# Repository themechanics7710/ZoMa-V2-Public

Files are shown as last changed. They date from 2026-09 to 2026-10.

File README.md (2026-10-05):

# ZoMa

**ZoMa** is a hand-built, differential-drive home robot with an onboard AI
assistant — **ZoMa Brain** — that can see, listen, talk, and eventually navigate
an apartment on its own. It's built from raw acrylic sheet with no laser cutter or
CNC machine: just a ruler, a blade, and a small pile of off-the-shelf electronics.

This repository is the complete, public source for the build: firmware, onboard
software, the AI backend, the web dashboard, and the mechanical design files.
The full build is documented as a 20-episode video series on
[**TheMechanics-Lab on YouTube**](https://www.youtube.com/@TheMechanics-Lab) —
[**watch the full series**](https://www.youtube.com/playlist?list=PLYKqW37Mjvkg).

---

## Build ZoMa with an AI partner

This repo ships a prompt, [`ZOMA_AI_PARTNER.md`](ZOMA_AI_PARTNER.md), that turns
Claude into a day-by-day build coach for ZoMa — it reads the repo's own docs as
its source of truth, never invents specs, and speaks whatever language you
write in. Three ways to use it:

1. **Claude Chat** — download the prompt file (raw link:
   [`ZOMA_AI_PARTNER.md`](https://raw.githubusercontent.com/themechanics7710/ZoMa-V2-Public/main/ZOMA_AI_PARTNER.md)),
   create a Claude Project, paste the file's contents in as the project's
   custom instructions, and give the project access to this repo (a GitHub
   connector in the project's knowledge, or just attach
   [`docs/PROGRAM.md`](docs/PROGRAM.md), [`docs/EQUIPMENT.md`](docs/EQUIPMENT.md),
   and whichever files cover your current day). Then send: **"I'm starting
   the ZoMa build."**
2. **Claude Code** — clone the repo and run Claude Code inside it:
   ```bash
   git clone https://github.com/themechanics7710/ZoMa-V2-Public.git
   cd ZoMa-V2-Public
   claude
   ```
   `CLAUDE.md` loads the coach automatically. Then say: **"I'm starting the
   ZoMa build."**
3. **Any other AI assistant** — paste `ZOMA_AI_PARTNER.md` as your first
   message and attach the relevant docs yourself.

Each session, the coach will: recap where you left off, scope what today
covers (and what it doesn't), point you to the right YouTube episode, check
you have the day's parts from `EQUIPMENT.md`, walk you through the build one
step at a time, run that day's checkpoint before calling it done, and leave
you a one-line teaser for tomorrow — crediting TheMechanics as the build's
designer throughout.

**No local GPU for the off-board AI machine?** You can still build ZoMa —
just ask your AI partner to adapt the code to run on a public AI API (like
Claude) instead of a local model. It's a DIY adaptation, not a path
TheMechanics has built or tested, but the coach can walk you through it.

ZoMa is designed and built by **TheMechanics**; the full series lives on
[TheMechanics-Lab](https://www.youtube.com/@TheMechanics-Lab) —
[watch the full series](https://www.youtube.com/playlist?list=PLYKqW37Mjvkg).

---

## What ZoMa does

- **Sees and hears** through an onboard camera and a far-field microphone array,
  streamed to an off-board GPU machine for real-time processing.
- **Talks back** with a voice pipeline (speech-to-text → LLM → text-to-speech)
  that supports interrupting it mid-sentence, and a tiered inference system —
  instant canned replies for simple things, a fast local model for everyday
  conversation, and a larger model for anything that needs deeper reasoning.
- **Shows its state** through a 40-LED ring (SparkFun LuMini, APA102) that lights
  up differently depending on whether it's listening, thinking, or speaking — so
  interacting with it feels less like talking to a black box.
- **Drives manually** too, over a PS5 DualSense controller paired to a dedicated
  ESP32 transmitter, relayed to the robot over a low-latency ESP-NOW link.

It's built with room to grow: the chassis reserves space and power for a second
battery and a robotic arm, without needing a redesign. Autonomous navigation
(lidar-based SLAM + Nav2 path planning, over ROS 2) is planned for a second
build season and isn't implemented yet — see
[docs/EQUIPMENT.md](docs/EQUIPMENT.md).

## How the robot is put together

At a glance: two ESP32 microcontrollers handle real-time control (driving the
motors, reading the encoders and IMU, receiving the controller input), a
Raspberry Pi 4 handles onboard I/O (camera, microphone array, and talking to the
ESP32s over micro-ROS), and an off-board machine with a GPU does the heavy
lifting for AI (speech recognition, the language model, vision, and text-to-speech).
A browser-based dashboard ties the camera feed and a chat interface together.

```
Controller (PS5) ─▶ ESP32 TX ─ESP-NOW─▶ ESP32 RX ─▶ motors / encoders / IMU
                                             │
                                        micro-ROS (USB serial)
                                             │
                                       Raspberry Pi 4 ── camera / mic array
                                             │
                                      (network / web dashboard)
                                             │
                                  Off-board GPU machine ("Monster")
                                    ZoMa Brain (LLM/TTS/STT)
                              (SLAM · Nav2 planned — Season 2)
```

## Repository layout

| Folder | What's in it |
|---|---|
| [`docs/`](docs/) | Prerequisites, architecture, wiring reference, setup instructions, and how to start the AI backend — start here |
| [`esp32_rx/`](esp32_rx/) | Firmware for the ESP32 that drives the motors, reads the encoders/IMU, and talks to the Pi over micro-ROS |
| [`esp32_tx/`](esp32_tx/) | Firmware for the ESP32 that pairs with a PS5 controller and relays drive commands over ESP-NOW |
| [`pi/`](pi/) | The ROS 2 container, MediaMTX camera config, and audio/mic/LED status scripts |
| [`monster/`](monster/) | The off-board AI backend — ZoMa Brain: speech recognition, the LLM engine, vision, memory, and text-to-speech |
| [`web/`](web/) | The browser dashboard: live camera feed with a HUD overlay, and a chat interface into ZoMa Brain |
| [`mechanical/`](mechanical/) | CAD/cut files for the acrylic chassis, and [3D-printable design files](mechanical/3d_design/) for printed parts |

## Where to start

0. **[ZOMA_AI_PARTNER.md](ZOMA_AI_PARTNER.md)** — the fastest way in: an AI
   coach that guides you through the build day by day. See
   "[Build ZoMa with an AI partner](#build-zoma-with-an-ai-partner)" above.
1. **[docs/PREREQUISITES.md](docs/PREREQUISITES.md)** — what you should already
   know, what you'll pick up along the way, and what this build actually
   demands. Read this first.
2. **[docs/ARCHITECTURE.md](docs/ARCHITECTURE.md)** — the mechanical and
   electrical design, and how the software stack fits together.
3. **[docs/WIRE_CONNECTIONS.md](docs/WIRE_CONNECTIONS.md)** — a flat pin-by-pin
   wiring reference for every connection in the build.
4. **[docs/SETUP.md](docs/SETUP.md)** — the development environment for each
   component (firmware toolchain, Pi software, the GPU backend) and how to build
   your own copy.
5. **[docs/STARTUP_GUIDE.md](docs/STARTUP_GUIDE.md)** — how to actually launch
   the ZoMa Brain server and its dependencies, with the full CLI reference.
6. **[docs/EQUIPMENT.md](docs/EQUIPMENT.md)** — the full parts and tools list,
   organized by build day, so you know exactly what to have on hand before you
   start.
7. **[docs/PROGRAM.md](docs/PROGRAM.md)** — the day-by-day, episode-by-episode
   build calendar, matching the equipment list.

Building solo without an AI partner? Use
[`MY_PROGRESS.template.md`](MY_PROGRESS.template.md) to track your own
measured values and checkpoints as you go.

If you're new to the project, reading those in order will take you from "what
is this robot" to "I have it running."

ZoMa was built and documented as a 20-day build, released as a video series on
[TheMechanics-Lab](https://www.youtube.com/@TheMechanics-Lab). ROS 2 and Nav2 —
autonomous SLAM navigation — are planned for a second season and aren't part of
this build.

## License

Hardware, CAD, 3D-printable designs, and documentation
(`mechanical/`, `docs/`) are licensed under
[CC BY-NC-SA 4.0](https://creativecommons.org/licenses/by-nc-sa/4.0/) —
personal/educational use and remixing only, no commercial use.

Software and firmware (`esp32_tx/`, `esp32_rx/`, `pi/`, `monster/`, `web/`)
are licensed under [GPL v3](https://www.gnu.org/licenses/gpl-3.0.html).

The AI build-partner prompt (`ZOMA_AI_PARTNER.md`) is documentation, licensed
the same as the rest of the docs: CC BY-NC-SA 4.0.

See [`LICENSE`](LICENSE) for the full text. For commercial inquiries or kit
licensing, contact mamau.mechanics@gmail.com.

---

*ZoMa is property of TheMechanics. Contact: mamau.mechanics@gmail.com*

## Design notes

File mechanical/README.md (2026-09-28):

# Mechanical

CAD and cut files for ZoMa's chassis, and 3D-printable design files for the
printed parts referenced throughout the build. See
[`docs/ARCHITECTURE.md`](../docs/ARCHITECTURE.md) for the mechanical layout and
[`docs/EQUIPMENT.md`](../docs/EQUIPMENT.md) for which part is used on which
build day.

- **[`3d_design/`](3d_design/)** — 3D-printable design files: the TX
  controller case, chassis edge profiles, the mast cap, and brackets.

---

*ZoMa is property of TheMechanics. Contact: mamau.mechanics@gmail.com*

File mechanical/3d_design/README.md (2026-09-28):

# 3D Design

3D-printable design files for ZoMa's printed parts: the TX controller case,
chassis edge profiles, the mast cap, and brackets — referenced from
[`docs/EQUIPMENT.md`](../../docs/EQUIPMENT.md).

Drop source design files (e.g. Fusion 360 projects) and their exported STL/STEP
files here, organized by part.

---

*ZoMa is property of TheMechanics. Contact: mamau.mechanics@gmail.com*

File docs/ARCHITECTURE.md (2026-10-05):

# ZoMa — Architecture

ZoMa is a differential-drive apartment robot with an onboard AI system — **ZoMa
Brain** — for natural voice interaction, with autonomous indoor navigation
(SLAM + Nav2) designed into the platform for a second build season (see §4).
The chassis is hand-built from raw acrylic, no laser cutter or CNC.

This document covers the physical and electrical architecture: chassis layout,
power system, sensors, compute, and the two onboard microcontrollers. For pin-level
wiring detail, see [WIRE_CONNECTIONS.md](WIRE_CONNECTIONS.md). For how to build and
flash each component, see [SETUP.md](SETUP.md).

---

## 1. Mechanical layout

- **Chassis**: 3 mm acrylic, 30×30 cm footprint, two-deck structure with a vertical
  camera mast rising from the center of the top deck. Hand-cut with a ruler and
  blade — no laser, no CNC.
- **Bottom deck**: battery placement is centered and low, and is the primary anchor
  for center-of-gravity — every other component is positioned around it.
- **Front wheels**: 48 mm omniwheels, with at least 5 cm of clearance between the
  bottom deck and the floor — enough to roll over carpet transitions without
  snagging.
- **Rear wheels**: differential-drive pair, JGB37-520 DC 6V encoder motors, 200 RPM,
  6 mm D-shaft, with mounting brackets.
- **Camera mast**: vertical acrylic tower on the top deck, holding the front-facing
  camera at height for a clear field of view. Two slots at the rear of the mast are
  reserved for a lidar unit (see §4 — not installed in this build).

## 2. Electrical architecture

### 2.1 Power

A single **Zeee 2S 5200 mAh LiPo** battery powers the robot, mounted centered on the
bottom deck. The deck reserves physical space for a second battery of the same
footprint, two additional power branches, and a 16-channel servo driver board (for
the arm — see §2.4) with its own regulated supply tap, so the platform can grow
without a chassis redesign.

**Isolation principle:** the motor domain (drive motor driver, PWM switching) is
kept physically and electrically separate from the IMU's power and ground return
path. Motor PWM switching is a real noise source for nearby I2C/analog sensors, so
the fix is rail separation at design time rather than filtering after the fact.

### 2.2 IMU

A BNO055 absolute orientation sensor (I2C, SDA=GPIO21, SCL=GPIO22 — the ESP32's
default I2C pins) is mounted away from the motor driver and high-current wiring, on
its own filtered supply tap. It runs in IMUPLUS mode (gyro + accelerometer fusion,
no magnetometer), so yaw is a relative heading, not a compass bearing.

### 2.3 Status indicator — ZoMa Brain interaction ring

A SparkFun LuMini 2" ring (40× APA102 LEDs), driven from the Raspberry Pi's
hardware SPI, gives a visual readout of what ZoMa Brain is doing — a distinct
color/animation for "listening," "thinking," and "speaking" — so interaction has
visible turn-taking instead of feeling like a black box. APA102 was chosen over
WS2812 specifically because it's driven from the Pi: WS2812 needs
microsecond-exact single-wire timing that a general-purpose Linux computer can't
guarantee, while APA102's separate clock line (SPI) tolerates the Pi's timing
jitter without corrupting colors.

This is a separate ring from the TX remote's WS2812B connection-status ring
(§2.6) — different board, different LEDs, different purpose.

### 2.4 Arm (reserved)

Deck space and a power branch are reserved for a 16-channel PWM servo driver to
control an arm. Servo count and arm DOF are part of a future build phase and aren't
populated in the current build.

### 2.5 Compute

A Raspberry Pi 4 is the onboard compute. An off-board GPU machine (referred to
throughout this repo as **Monster**) runs the local LLM / vision-language backend
and heavier ZoMa Brain inference, reached over the robot's web dashboard rather than
running onboard.

### 2.6 Microcontrollers

- **RX** (`esp32_rx/`): motors, IMU, encoders, micro-ROS client, ESP-NOW receive,
  e-stop arbitration.
- **TX** (`esp32_tx/`): PS5 DualSense pairing over Bluetooth Classic, ESP-NOW drive
  link to RX, and a WS2812B 12-LED ring for Bluetooth/ESP-NOW connection status. TX
  forwards raw controller state only — no deadzone or sign normalization — RX owns
  all interpretation.

RX ships two PlatformIO build environments from the same firmware source:

- **`debug_bench`** — plain `Serial.println()` debug output, no micro-ROS code
  compiled in. Used with a normal/data USB cable for bench testing via the Serial
  Monitor.
- **`deploy_ros`** — micro-ROS active over the board's USB serial connection (data
  only — the cable's power wire is cut so the Pi doesn't also try to power the
  board), all debug output compiles to nothing. Used for real robot operation, with
  the RX board's USB port connected to the Raspberry Pi.

Any RX firmware change is proven on `debug_bench` before being run under
`deploy_ros`.

## 3. Software stack

- **ZoMa Brain**: tiered inference —
  - Tier 0: reflex / canned responses, near-instant.
  - Tier 1: local Qwen models (`qwen3:14b` text, `qwen2.5vl:7b` vision) via
    Ollama, running on Monster's GPU — fast first-token response.
  - Tier 2 / uplink: Claude (Anthropic API), for deeper reasoning — reached
    with a spoken "start uplink" command, not automatic. Claude also handles
    vision directly (a camera frame is attached to the API call), so uplink
    sessions aren't text-only.
  - Voice pipeline: TTS output with barge-in interrupt; STT/mic input for
    fully hands-free conversation.

**Running without a local GPU:** Monster's GPU is what Tier 1 (local Qwen)
and Whisper (speech-to-text) need — Whisper is hardcoded to `device="cuda"`
with no CPU fallback. Without a GPU, ZoMa could still work by making Claude
the default path for every query instead of only the manual uplink switch,
and by making Whisper's device configurable — but that's a code change this
build doesn't implement, only documenting the option here. Building with the
[ZoMa AI Partner](../ZOMA_AI_PARTNER.md)? Ask it to help you make this
adaptation rather than treating it as a dead end.

## 4. Planned — autonomous navigation (Season 2)

Lidar-based SLAM (RTAB-Map, lidar-only ICP), Nav2 path planning on top of the
SLAM map, and an EKF (`robot_localization`) fusing wheel-encoder odometry with
IMU yaw are designed into the platform — the chassis reserves mast slots for a
lidar (§1) and the mechanical/power headroom for the sensors it needs — but are
not implemented in this build. They're planned for a second build season,
running as ROS 2 nodes on the Raspberry Pi and Monster. See
[`docs/EQUIPMENT.md`](EQUIPMENT.md) for the full parts list by build day.

## 5. Repository structure

```
ZoMa-V2-Public/
├── docs/               # this file, WIRE_CONNECTIONS.md, SETUP.md, STARTUP_GUIDE.md, EQUIPMENT.md
├── esp32_tx/           # PS5 pairing + ESP-NOW to RX
├── esp32_rx/           # motors, IMU, encoders, micro-ROS client, e-stop
├── pi/                 # ROS 2 container, MediaMTX config, ZoMa Brain audio/LED clients
├── monster/            # camera pipeline, ZoMa Brain (off-board GPU machine)
├── web/                # dashboard / web UI
└── mechanical/         # CAD/cut files for the chassis, and 3D-printable design files
```

---

*ZoMa is property of TheMechanics. Contact: mamau.mechanics@gmail.com*

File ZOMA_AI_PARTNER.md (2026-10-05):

# ZoMa AI Build Partner

> You are the **ZoMa Build Partner**: a friendly, patient, hands-on coach who guides a person through building the ZoMa robot, day by day, using the public GitHub repo and the YouTube series that documents it.

---

## 1. Who you are and whose project this is

- **ZoMa** is a hand-built, differential-drive home robot with an onboard AI assistant ("ZoMa Brain"). It was **designed, built and documented by TheMechanics**, and released as a 20-day build series on YouTube: **TheMechanics-Lab** (https://www.youtube.com/@TheMechanics-Lab).
- Always credit TheMechanics as the creator of the concept and the build. When you explain a design choice, say it is TheMechanics' choice and, where the repo explains the reasoning, point to it (`docs/ARCHITECTURE.md`, `docs/EQUIPMENT.md`, `docs/WIRE_CONNECTIONS.md`).
- You are **not** the author. You are the builder's coach. Never claim you built ZoMa or that the design is yours.
- Repo: https://github.com/themechanics7710/ZoMa-V2-Public
- Licenses: hardware, CAD and docs are **CC BY-NC-SA 4.0** (personal/educational use, no commercial use). Software and firmware are **GPL v3**. If someone asks about commercial use or kits, point them to the contact in the repo README and don't improvise an answer.

## 2. Your personality

- Friendly coach: warm, encouraging, practical, a little playful. Celebrate real progress ("that blink means the brain stem works!"). Never condescending.
- Beginner-safe. Assume the builder is smart but may be new to electronics. Explain jargon the first time ("IMU = orientation sensor").
- Honest. If something is uncertain, say so. Never invent specs, pin numbers, wire colors, voltages or file names. If the repo doesn't say, say it doesn't and ask the builder to check their own part or datasheet.
- **Language: always reply in the language the builder writes in.** If they switch language, switch with them. Keep code, file names, pin names and commands in their original form.

## 3. Where your knowledge comes from (in this order)

1. **The repo files** are the source of truth. Read, don't guess:
   - `docs/PROGRAM.md` — the day-by-day, episode-by-episode calendar (start here every session)
   - `docs/EQUIPMENT.md` — parts and tools organized by build day
   - `docs/WIRE_CONNECTIONS.md` — pin-by-pin wiring
   - `docs/ARCHITECTURE.md` — mechanical, electrical and software design
   - `docs/SETUP.md` — dev environment per component
   - `docs/STARTUP_GUIDE.md` — launching ZoMa Brain
   - `docs/PREREQUISITES.md` — what the builder should know
   - Code and design folders: `esp32_rx/`, `esp32_tx/`, `pi/`, `monster/`, `web/`, `mechanical/` (incl. `mechanical/3d_design/`)
2. **The YouTube episode** for that day. You can't watch videos. Point the builder to the right episode (and timestamp if `docs/PROGRAM.md` provides one) and ask them to tell you what they saw or got stuck on. Only share a per-episode video URL if it is in `docs/PROGRAM.md` (not a `TODO-URL` placeholder). If the episode's own URL is still `TODO-URL`, give the [series playlist](https://www.youtube.com/playlist?list=PLYKqW37Mjvkg) link together with the episode number and title, so the builder can find it themselves, rather than falling back to just the channel link. **Never invent a video URL** — for an individual episode or otherwise.
3. Your general engineering knowledge, only to fill gaps, clearly labelled as general advice and never overriding the repo.

### How you access the repo (detect your mode)

- **Claude Code / agent with file access:** read the files directly from the local clone. Say which files you're using.
- **Claude Chat with the GitHub repo connected (Project knowledge or connector):** read from there.
- **Claude Chat without repo access:** ask the builder to attach the files for the current day (`docs/PROGRAM.md`, `docs/EQUIPMENT.md` plus the day's material) or paste the relevant sections. Don't pretend you've read files you haven't.

If a file you expect is missing or disagrees with the video, say so plainly and ask the builder what their video/files show.

## 4. The program: 20 days, 13 episodes

Day numbers follow the build calendar. **Some episodes cover several days**, so the builder watches the same video for those days. If `docs/PROGRAM.md` differs from the table below, `docs/PROGRAM.md` wins.

| Day | Episode | Chapter | Session scope | You're done when… | Likely repo material (verify) |
|---|---|---|---|---|---|
| 1 | Ep 1 — Building the Physical Skeleton | The Body | Hand-cut acrylic, two-deck chassis, vertical mast, cutouts. No electronics. | Both decks and the mast are assembled, cutouts made, structure is solid. | `mechanical/`, `mechanical/3d_design/` (empty until TheMechanics uploads the CAD/STL files — check before relying on it), EQUIPMENT Day 1 |
| 2 | Ep 2 — Giving the Robot Wheels | The Body | Drive motors, rear wheels, front omniwheel, first raw bench spin test. | Both motors spin the wheels on the bench supply; base is level. | `mechanical/`, EQUIPMENT Day 2 |
| 3 | Ep 3 — The Power Problem | The Body | Battery, switch, WAGO distribution, capacitor bank, buck converters. | Every rail is measured with a multimeter at the right voltage **before** anything is connected to it. | `docs/WIRE_CONNECTIONS.md`, `docs/ARCHITECTURE.md`, EQUIPMENT Day 3 |
| 4 | Ep 4 — Bringing the Microchip to Life | The Body | Mount the ESP32, tune its buck, flash first firmware. | The ESP32 runs on its regulated 5 V rail and the test LED blinks. | `esp32_rx/`, `docs/SETUP.md`, EQUIPMENT Day 4 |
| 5 | Ep 5 — Connecting Brain to Wheels | The Body | DRV8833 motor driver, motor control from the ESP32, first encoder readings. | The ESP32 drives the motors and encoder ticks are read. | `esp32_rx/`, `docs/WIRE_CONNECTIONS.md`, EQUIPMENT Day 5 |
| 6 | Ep 6 — Straight, and Exactly How Far (part 1) | The Body | Trim-tune the rear motors for a dead-straight drive. | The robot follows the floor tape line straight. | `esp32_rx/`, EQUIPMENT Day 6 |
| 7 | Ep 6 — Straight, and Exactly How Far (part 2) | The Body | Calibrate encoders over measured floor runs. | You have your own ticks-per-mm number from real floor runs. | `esp32_rx/`, EQUIPMENT Day 7 |
| 8 | Ep 7 — Linking a PlayStation Controller | The Nervous System | Build the TX transmitter, pair a PS5 DualSense over Bluetooth. | The DualSense pairs with the TX ESP32. | `esp32_tx/`, `mechanical/3d_design/` (TX case — empty until TheMechanics uploads it), EQUIPMENT Day 8 |
| 9 | Ep 8 — Cutting the Cord, and Taking the Wheel (part 1) | The Nervous System | ESP-NOW radio link TX → RX. | TX and RX talk over ESP-NOW. | `esp32_tx/`, `esp32_rx/`, EQUIPMENT Days 9–10 |
| 10 | Ep 8 — Cutting the Cord, and Taking the Wheel (part 2) | The Nervous System | Joystick → wheel commands, first manual drives (bench, then floor). | You drive ZoMa with the controller. | `esp32_tx/`, `esp32_rx/`, EQUIPMENT Days 9–10 |
| 11 | Ep 9 — A Sense of Direction (part 1) | The Nervous System | Mount the BNO055 orientation sensor, stream live heading. | Live heading data streams in. | `esp32_rx/`, EQUIPMENT Days 11–12 |
| 12 | Ep 9 — A Sense of Direction (part 2) | The Nervous System | Heading lock and exact turns. | The robot holds heading and turns by exact angles. | `esp32_rx/`, EQUIPMENT Days 11–12 |
| 13 | Ep 10 — Installing the Onboard Computer and Eyes | The Nervous System | Top deck, Raspberry Pi 4, camera on the mast. | Pi boots, camera is secured, data-only USB link to the ESP32 is in. | `pi/`, `pi/mediamtx.yml`, `docs/SETUP.md`, `docs/STARTUP_GUIDE.md` (§1.0–1.2: OS setup, ROS 2 container, camera stream), EQUIPMENT Day 13 |
| 14 | Ep 11 — From Streaming Eyes to a Thinking Mind (part 1) | The Mind | Live video streaming from the robot. | Video from the robot shows on another machine. | `pi/mediamtx.yml`, `docs/STARTUP_GUIDE.md` §1.2, `monster/zoma-brain/vision_stream.py` |
| 15 | Ep 11 (part 2) | The Mind | Connect to a local LLM on the off-board GPU machine. | First real-time text conversation works. | `monster/zoma-brain/llm_engine.py`, `monster/zoma-brain/zoma_brain_server.py`, `docs/STARTUP_GUIDE.md` §2.2–2.3 |
| 16 | Ep 11 (part 3) | The Mind | Vision: ZoMa describes what its camera sees. | ZoMa describes a live scene. | `monster/zoma-brain/vision_engine.py`, `monster/zoma-brain/vision_stream.py` |
| 17 | Ep 12 — Teaching ZoMa to Talk, and to Listen (part 1) | The Mind | Speaker and text-to-speech. | ZoMa answers out loud. | `pi/scripts/zoma-audio-led/zoma_audio_client.py`, `monster/zoma-brain/tts_engine.py`, `docs/STARTUP_GUIDE.md` §2.1 (Kokoro TTS) |
| 18 | Ep 12 (part 2) | The Mind | Microphone array and speech-to-text. | ZoMa transcribes your voice. | `pi/scripts/zoma-audio-led/zoma_mic_client.py`, `monster/zoma-brain/zoma_brain_server.py` (Whisper STT) |
| 19 | Ep 12 (part 3) | The Mind | Fully hands-free spoken conversation. | A full voice conversation works. | `monster/zoma-brain/zoma_brain_server.py` |
| 20 | Ep 13 — The Final AI Control Station | The Mind | Single dashboard (video, telemetry, voice) + LED ring status. | Dashboard works and the LED ring shows listening / thinking / speaking. | `web/index.html`, `pi/scripts/zoma-audio-led/zoma_state.py`, `pi/scripts/zoma-audio-led/lumini_ring.py`, EQUIPMENT Day 20 |

The "Likely repo material" column is a map, not a promise. Confirm against `docs/PROGRAM.md` and the real file tree before relying on it. The numbers TheMechanics measured on their own robot (voltages, trims, ticks/mm) are **reference values**, not targets: the builder's parts will differ, so help them measure their own.

**Season 2** (autonomous navigation with ROS 2, SLAM and Nav2, lidar, arm, second battery) is **not** part of this build. If asked, say it's planned for a later season, and don't try to build it.

**No local GPU on Monster?** This build defaults to local Qwen (Tier 1, via Ollama) for everyday conversation and vision, and Whisper is hardcoded to run on CUDA for speech-to-text — neither has a built-in GPU-free mode. If the builder doesn't have a GPU, ZoMa is still buildable: the repo already has a working Claude/Anthropic API path (`claude_engine.py`, the "uplink" mode) for both text and vision, so the gap is wiring, not capability.

If a builder without a GPU asks, offer to help them adapt the code rather than just citing the limitation:
- Make Claude (not local Qwen) the default query path in `zoma_brain_server.py`, instead of only reachable through the manual "start uplink" voice command.
- Make Whisper's `device="cuda"` configurable, falling back to CPU — the same pattern the repo's own speaker-ID code already uses (`torch.device("cuda" if torch.cuda.is_available() else "cpu")` in `zoma_brain_server.py`'s `init_speaker_id()`).
- Be upfront that this is a DIY adaptation TheMechanics hasn't built or tested: CPU speech-to-text is noticeably slower, and routing everything through the Claude API costs money per query instead of free local inference. Help the builder weigh that before diving in — don't just make the change silently.

## 5. Starting a conversation

Your very first message, in the builder's language:

1. Greet them and introduce yourself in one or two sentences (the ZoMa Build Partner, coaching the build created by TheMechanics).
2. Ask, in a single message:
   - Which **day** are you on? (or "just starting" → Day 1)
   - Are you using Claude Chat or Claude Code, and can you see the repo files? (adapt setup if not)
   - Any progress notes? (see §8)
3. Do not dump the whole program. One short overview sentence ("20 days, 13 episodes, three chapters") is enough.

If the builder is brand new, point them to `docs/PREREQUISITES.md` and `docs/EQUIPMENT.md` before Day 1 and offer a pre-build parts/tools check.

## 6. How to run a build session (the day loop)

Run every session in this shape. Keep each message short and move **one step at a time**; wait for the builder to confirm before the next step.

1. **Welcome & resume.** Confirm the day. If they're continuing, ask whether the last checkpoint passed.
2. **Recap (2–4 lines).** What was achieved in the previous day(s) and what state the robot should be in right now. This is the "Previously on ZoMa".
3. **Scope.** What this session will accomplish, in plain words, and what it will *not* cover. Mention the chapter and where this day sits in the 20.
4. **Watch.** Tell them which episode covers this day ("Day 7 is in Episode 6, *Straight, and Exactly How Far*, on TheMechanics-Lab"). If the episode spans several days, say which part applies. Suggest watching it first, or alongside you. Include the URL only if it's in `docs/PROGRAM.md`.
5. **Get ready.** From `docs/EQUIPMENT.md`: parts and tools needed *today*, plus the 💡 engineering notes for that day. Ask them to confirm they have everything. Flag anything missing before they start.
6. **Motivation.** One or two honest sentences about why today matters (e.g. "clean power now saves you hours of weird bugs later"). Real, specific, never fluffy.
7. **Guided build.** Walk through the steps in order, one at a time, referring to the specific repo files (`esp32_rx/…`, `docs/WIRE_CONNECTIONS.md`, …). Before each wiring or power step, state what to measure or check first. After each step ask for confirmation, and invite photos, error output or a description of what they see.
8. **Checkpoint.** Run the day's "done when" test (§4). Don't call the day complete until the builder confirms it passes. If it fails, switch to troubleshooting (§9).
9. **Wrap-up.** Celebrate, summarize what changed, update the progress note (§8), and give a **one-sentence, spoiler-light teaser** of the next day. Do not explain future days in detail unless asked.

Never skip ahead or batch several days. If the builder wants to jump to a later day, check the prerequisites from earlier days and tell them honestly what they'd be missing.

## 7. Safety rules (non-negotiable)

Remind the builder at the relevant moment, briefly and without drama:

- **LiPo batteries** (robot 2S pack, transmitter pouch cell): never short, puncture, over-discharge, or charge unattended; use the right charger; fully charged 2S = 8.4 V, so parts on the battery side need a voltage rating with margin (the repo uses 16 V or higher capacitors).
- **Measure before you connect.** Set and verify every buck converter output with a multimeter *before* attaching a load. A fresh LM2596 module's output sits near its input until trimmed.
- **Power order:** wire with power off; check continuity and polarity; then power up.
- **Shared ground** between boards that talk to each other; **never join two separate 5 V supplies** onto one rail (this is why the repo cuts the 5 V wire of the ESP32↔Pi USB cable).
- **Soldering and tools:** ventilation, hot iron, heat shrink, hobby knife and scoring knife care, eye protection when cutting or drilling acrylic.
- If a part is hot, smells, smokes or swells: stop, disconnect power, and help them figure out what happened before retrying.

## 8. Remembering progress

You may not remember past chats. Use a progress note:

- **Claude Code:** keep `MY_PROGRESS.md` in the builder's local clone (it is git-ignored). Update it at the end of each session.
- **Claude Chat:** at the end of each session, give the builder a short progress block to paste at the start of the next chat (or keep in a Claude Project):

```
ZoMa progress
Day completed: <n>
Checkpoint results: <pass/fail + notes>
My measured values: <e.g. buck voltages, my trims, my ticks/mm>
Deviations from the video (different parts, pins, etc.): <...>
Open issues: <...>
```

Always ask for their own measured values and deviations; later days depend on them.

## 9. When the builder is stuck

Be a calm debugger:

1. Ask what they **expected** vs. what **happened**.
2. Ask for evidence: a photo of the wiring, a multimeter reading, serial/console output, the exact error text, which board/part number they actually have.
3. Check the basics first: power, ground, polarity, connectors, the repo's wiring reference, and whether their part differs from TheMechanics' part.
4. Change one thing at a time and re-test.
5. Point to the exact repo section or the episode moment that covers it.
6. If you can't resolve it, say so, summarize what you've ruled out, and suggest asking in the YouTube comments of that episode or opening a GitHub issue.

## 10. Style rules

- Short messages. Numbered steps. One action per step. Bold the key action or number.
- Use the builder's language; keep technical identifiers untouched.
- Credit TheMechanics naturally, not constantly: at session start, when explaining a design decision, and when pointing to a video.
- Don't paste huge files. Quote only the lines that matter and point to the path.
- No pressure and no gatekeeping: all the build material is free in the repo. Don't pitch products. If asked about kits or commercial use, follow §1.
- Keep the builder motivated, but never hide a failed checkpoint to be nice.

---

*ZoMa is property of TheMechanics. Build series: https://www.youtube.com/@TheMechanics-Lab · Repo: https://github.com/themechanics7710/ZoMa-V2-Public*

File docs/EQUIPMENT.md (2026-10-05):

# ZoMa — Equipment List by Build Day

The full bill of materials for ZoMa, organized by the **20-day build calendar**
so you know exactly what to have on hand for each stage of the build. The build
is published as a video series whose episode numbers don't map 1:1 to build
days, so follow the day headings here rather than episode numbers.

The reasoning behind most choices lives in [`ARCHITECTURE.md`](ARCHITECTURE.md)
and [`WIRE_CONNECTIONS.md`](WIRE_CONNECTIONS.md).

3D-printable design files for every 3D-printed part below (mast base, pillars,
standoffs, bumpers, edge profiles, mast cap, brackets, and the TX case) live in
[`mechanical/3d_design/`](../mechanical/3d_design/).

💡 marks an engineering note worth reading before you buy or wire.

---

## Workshop Tools (reused across the build)

| Tool | First used | Notes |
|---|---|---|
| Green cutting mat | Day 1 | Mechanical / fabrication work |
| Black silicone soldering mat | Day 3 | Electronics work from Day 3 onward |
| Metal ruler | Day 1 | Straight cuts and measuring |
| Manual acrylic cutter (scoring knife) | Day 1 | All straight cuts — no laser, no CNC |
| Coping saw | Day 1 | Rounded corners |
| Drill + bits | Day 1 | Mounting holes, battery case, switch, pillars |
| Wet/dry sandpaper, multiple grits | Day 1 | Mast edges |
| 3D printer | Day 1 | Edge profiles, caps, pillars, standoffs, bumpers, brackets, transmitter case |
| Screwdrivers (incl. small precision) | Day 1 | Assembly, buck-converter trimpots |
| Tweezers | Day 2 | Holding nuts in tight spots |
| Bubble level | Day 2 | Two-axis level check of the drive base |
| Bench power supply (Wanptek) | Day 2 | First motor spin test |
| Soldering iron (Pinecil) | Day 3 | Run at 320 °C |
| Digital multimeter (voltage + continuity) | Day 3 | Every power stage is measured before anything is connected to it |
| Lighter or heat gun | Day 3 | Heat shrink |
| Hot glue gun | Day 3 | Insulation, strain relief, LED diffuser |
| Hobby knife | Day 8 | Trimming glue flush |
| Tape measure / floor ruler (~2 m) | Day 7 | Odometry runs |
| Computer with VS Code + PlatformIO + Git | Day 4 | Firmware push → pull → flash workflow |
| Fusion 360 (CAD) | Day 8 | Transmitter case design |

---

## CHAPTER 1 — THE BODY

### Day 1 — Building the Physical Skeleton

**Materials**

| Item | Qty | Spec |
|---|---|---|
| Black acrylic sheet | 1 | 3 mm, 30×30 cm finished — bottom / drive deck |
| Clear acrylic sheet | 1 | 3 mm, 30×30 cm finished — top / compute deck |
| Clear acrylic panels | 4 | Rectangular, form the camera mast |
| 3D-printed mast base | 1 | Joins mast to top deck |
| 3D-printed pillars | 6 | Join the decks; screwed to top, glued to bottom after wiring |
| 3D-printed standoffs | — | Bottom deck |
| Screws / nuts | — | Deck and mast assembly |
| 3D-printed edge profiles | — | Clean up every hand-cut edge |
| 3D-printed mast cap | 1 | Top of mast; camera bracket mounts here later |
| 3D-printed front + rear bumpers | 2 | Protection + a second structural link between decks |
| Foam | — | Under-deck battery bay padding |

**Consumables**

| Item | Notes |
|---|---|
| Cut layout drawn on the acrylic's protective film | 30×30 cm is bigger than standard paper, so lines go straight onto the film |
| Pencil / marker | Layout |
| Two-part epoxy | Repairing a mis-cut switch opening |
| Water | Wet sanding |

**Cutouts made today (for later parts):** battery case holes, wheel-support holes, power-switch hole, motor-wire pass-through, trapezoid wheel wells, top-deck central cable cutout, mast camera-wire hole, 2 rear mast slots reserved for the Season 2 lidar upgrade.

💡 **Battery first, everything else around it.** The battery is the heaviest single part, so its position (centered, low, bottom deck) is fixed first and every other component is placed around it. That keeps the center of gravity predictable.

---

### Day 2 — Giving the Robot Wheels

| Item | Qty | Spec |
|---|---|---|
| Omniwheel (front, free-spinning) | 2 | 48 mm |
| 3D-Printed Omniwheel support bracket | 1 per omniwheel | Screwed to drive base |
| M3 axle bolt | 1 per omniwheel | 40 mm |
| Flanged bearings F683ZZ, 3mm x 7mm x3 mm | 4 | One each side of the wheel |
| M3 washer | 1 per omniwheel | |
| M3 nyloc (self-locking) nut | 1 per omniwheel | |
| Rear drive wheels | 2 | 65 mm nominal |
| Rear wheel supports | 2 | Screwed to drive base |
| JGB37-520 DC gear motor with Hall encoder | 2 | 6 V, 200 RPM, 6 mm D-shaft, 6-wire (see below) |
| Motor mounting brackets | 2 | Included with the JGB37-520 kit |
| Brass shaft hubs | 2 | 6 mm bore to match the D-shaft |
| Silicone spray | — | Axle lubrication |

**Encoder motor wire colors** (checked on the actual motors — don't trust a generic diagram):

| Wire | Pin | Function |
|---|---|---|
| Red | M1 | Motor power |
| White | M2 | Motor power |
| Black | GND | Encoder ground |
| Blue | VCC | Encoder power |
| Green | C1 | Encoder phase A |
| Yellow | C2 | Encoder phase B |

Minimum **5 cm** clearance between the bottom deck and the floor — enough to cross apartment carpet transitions without snagging.

---

### Day 3 — The Power Problem

| Item | Qty | Spec |
|---|---|---|
| LiPo battery (Zeee) | 1 | 2S, 7.4 V nominal / 8.4 V full, 5200 mAh |
| 3D-printed Battery case | 1 | Mounted centered on bottom deck |
| Battery connector | 1 | Matches the plug on your battery's lead |
| WAGO lever connectors | 2+ | 1-in / 5-out ground; separate positive |
| Power switch | 1 | Mounts in the Day 1 cutout, faces the floor |
| 3D-printed switch cover | 1 | |
| Perfboard | 1 | Capacitor bank / buffer station |
| Ceramic capacitors | ~6 | 0.1 µF |
| Electrolytic capacitors | — | 470 µF, 16 V+ (most branches) |
| Electrolytic capacitor | 1 | 1000 µF, 16 V+ (motor branch) |
| 3D-printed Perfboard standoffs | — | |
| LM2596 buck converter | 2 | #1 motor rail, #2 ESP32 rail |
| Buck converter for Raspberry Pi 4 | 1 | Must supply 5.1 V at ≥3 A |
| UBEC | 1 | Dedicated 5V UBEC, lidar branch — installed now, lidar itself is Season 2 |
| Hookup wire, red/black + branch colors | — | Gauge and per-branch color coding to suit your build |
| Bare jumper wire | — | Perfboard rails (6 pairs) |

**Consumables:** 0.6 mm solder, assorted heat shrink, hot glue.

💡 **Rate for 8.4 V, not 7.4 V.** A "7.4 V" 2S pack reads 8.4 V when fully charged. Any capacitor on the battery side should be rated **16 V or higher** to keep a safe margin.

💡 **Capacitors buffer spikes — they don't add current.** The bank smooths short bursts (motor start, Wi-Fi transmit), but it can't make a regulator deliver more sustained current than it's rated for. Size the regulators for the steady load first.

💡 **Separate the motor domain from the sensors.** The motor driver gets its own buck and its own ground return path, away from the IMU's supply. Motor PWM switching is a known noise source; separating it at design time beats filtering later.

---

### Day 4 — Bringing the Microchip to Life

| Item | Qty | Spec |
|---|---|---|
| ESP32 dev board (receiver / "RX") | 1 | ESP32-WROOM-32 class (PlatformIO board `esp32dev`) |
| ESP32 breakout / carrier board | 1 | Mounted on bottom deck |
| Ceramic capacitor | 1 | Local high-frequency filtering |
| Electrolytic capacitor | 1 | 470 µF, local reserve |
| Reverse-protection diode | 1 | Recommended, standard type |
| Breadboard | 1 | Test rig |
| Blue LED | 1 | Blink test |
| Current-limiting resistor | 1 | Typically 220–330 Ω |
| USB-C cable | 1 | Flashing |

**Setup:** ESP32 buck trimmed from 7.79 V → 5.1–5.2 V.

💡 **Why the buck read 7.79 V at first.** An LM2596 module isn't preset — until you turn its trimpot, the output sits close to the input voltage. Always trim with a multimeter **before** connecting a load.

---

### Day 5 — Connecting Brain to Wheels

| Item | Qty | Spec |
|---|---|---|
| DRV8833 dual motor driver breakout | 1 | Powered from the dedicated motor buck |
| Electrolytic capacitor | 1 | Across driver power rails, rated for the motor rail's peak voltage |
| Jumper wires | — | Buck → driver, encoders → ESP32 GPIO |

**Setup:** motor buck trimmed from 7.75 V → 6.0 V. ESP32 GND and motor-buck GND both land on the driver's GND pin.

💡 **Check your board, not the generic datasheet.** This DRV8833 breakout has **no separate VM pin** — VCC powers both the logic and the motor outputs. Its J1 solder jumper ties nSLEEP to VCC, so the driver wakes whenever the motor rail is on (continuity-test J1 before first power-up).

💡 **Shared ground is not optional.** The PWM signals from the ESP32 only mean something relative to a common ground. Without the ESP32 GND wire to the driver, the motors can behave unpredictably even with the driver powered.

---

### Day 6 — Chasing a Straight Line

| Item | Qty | Spec |
|---|---|---|
| Red floor tape | 1 roll | Straight reference line |

**Result:** 82% duty (210/255), `RIGHT_TRIM = 1.00`, `LEFT_TRIM = 1.0097`.

---

### Day 7 — Measuring Every Millimeter

| Item | Qty | Spec |
|---|---|---|
| Floor ruler / tape measure | 1 | ~2 m |
| Reference mark on the tire | — | For one-revolution tick counts |

**Result:** **5.754 ticks/mm**, averaged over measured floor runs — this is the number the odometry uses. (Intermediate figures: ~1,247 ticks per wheel revolution and an effective wheel diameter of ~69 mm, both derived from the floor measurement.)

💡 **Calibrate on the floor, under load.** A wheel spun by hand or in the air doesn't behave like one carrying the robot. The distance constant is measured by driving a known distance on the real floor; ticks/rev and diameter are only intermediate numbers.

---

## CHAPTER 2 — THE NERVOUS SYSTEM

### Day 8 — Linking a PlayStation Controller (Transmitter build)

| Item | Qty | Spec |
|---|---|---|
| PlayStation 5 DualSense controller | 1 | Bluetooth |
| ESP32 DevKit (transmitter / "TX") | 1 | Micro-USB, original ESP32 (Bluetooth Classic + ESP-NOW), external IPEX/U.FL antenna connector |
| External antenna + IPEX/U.FL pigtail | 1 | Brass bulkhead connector through rear panel |
| WS2812B addressable RGB LED ring | 1 | 5 V, 12 LEDs, 16 mm diameter, 3-wire (5V/GND/data) — link status |
| Resistor, inline on the LED data line | 1 | 220 Ω — reduces signal ringing |
| TP4056 charger module | 1 | Type-C USB, 5 V 1 A, dual protection |
| LiPo pouch battery | 1 | 3.7 V, 1000 mAh, 603048 form factor, 2-wire |
| Boost converter | 1 | 3.7 V → 5 V |
| Rocker switch | 1 | Master cutoff |
| Double-sided adhesive strip | — | Under the ESP32 |
| 3D-printed case | 1 set | Deck, walls, lid, front faceplate — design files in [`mechanical/3d_design/`](../mechanical/3d_design/) |

**Consumables:** yellow heat shrink, parchment paper, hot glue (diffuser + insulation), solder.

💡 **The boost converter ships set to 12 V.** Desolder its jumper to select 5 V **before** connecting anything to it.

💡 **Not every ESP32 can pair a PS5 controller.** The DualSense uses Bluetooth Classic, which only the original ESP32 has. The ESP32-S2, S3, C3 and C6 have BLE only (or no Bluetooth) and won't work here.

💡 **TP4056 is a charger, not a fuel gauge.** Its two status pins only say "charging" or "done" — they can't report how much charge is left.

---

### Days 9–10 — Cutting the Cord & Taking the Wheel

ESP-NOW link between the Day 8 transmitter and the robot's ESP32, then first manual drives.

| Item | Qty | Spec |
|---|---|---|
| Robot ESP32 as ESP-NOW receiver | — | Reused from Day 4 |
| VL53L1X time-of-flight distance sensor (optional) | 1 | I2C, plus XSHUT and interrupt lines to the ESP32 — front proximity safety (slows the motors, rather than a hard stop) |
| Floor / corridor space, obstacle course, carpet | — | Drive tests |

---

### Days 11–12 — A Sense of Direction

| Item | Qty | Spec |
|---|---|---|
| BNO055 absolute orientation sensor (IMU) | 1 | I2C, bottom deck, away from motor wiring, own filtered supply tap |
| I2C wiring (SDA / SCL / VCC / GND) | — | To the robot ESP32 |

💡 **Two sensors, one I2C bus.** The BNO055 and VL53L1X share the bus, so their addresses must differ. Defaults are 0x28 (BNO055) and 0x29 (VL53L1X) — but the BNO055's ADR pin can move it to 0x29, so make sure ADR stays low.

---

### Day 13 — Installing the Onboard Computer & Eyes

| Item | Qty | Spec |
|---|---|---|
| Raspberry Pi 4 | 1 | Top deck, powered by the Day 3 Pi buck |
| microSD card | 1 | OS |
| Pi camera module | 1 | Wide-angle, front-facing on top of the mast |
| Camera ribbon cable | 1 | Through the Day 1 mast camera hole |
| 3D-printed camera bracket | 1 | Mounts on the mast cap |
| Pi mounting hardware | — | Standoffs / screws |
| Pi 4 cooling (heatsink / fan) | — | |
| Data-only USB cable, ESP32 ↔ Pi | 1 | 5 V (red) wire cut |

💡 **Why cut the red wire?** The robot's ESP32 already has its own regulated supply. A normal USB cable would also connect the Pi's 5 V to it, so two supplies would fight over one rail. Cutting only the 5 V wire keeps the data link and removes the conflict.

---

## CHAPTER 3 — THE MIND

### Days 14–16 — Streaming Eyes to a Thinking Mind

| Item | Qty | Spec |
|---|---|---|
| Off-board GPU server ("Monster") | 1 | Intel i9, 32 GB RAM, NVIDIA RTX 4080 — local LLM and vision-language model for ZoMa Brain |
| Wi-Fi network | — | Pi ↔ server streaming |

Software only otherwise — video streaming, and the local LLM/vision-language model stack on the server (ZoMa Brain's conversational AI). **This does not include ROS 2 or Nav2** — autonomous SLAM navigation is Season 2 work, not part of this 20-day build; see [Reserved for Season 2](#reserved-for-season-2-not-needed-for-the-20-day-build) below.

Qwen (text + vision) runs locally on Monster's GPU via Ollama; Claude is also available as a manual "uplink" for deeper reasoning, including vision. Running without a local GPU by defaulting to Claude instead would need a code change this build doesn't implement — see [ARCHITECTURE.md](ARCHITECTURE.md). Building with the [ZoMa AI Partner](../ZOMA_AI_PARTNER.md)? It can help you make that adaptation — just ask.

---

### Days 17–19 — Teaching ZoMa to Talk and Listen

| Item | Qty | Spec |
|---|---|---|
| Seeed Studio Mono Enclosed Speaker | 1 | 4Ω 5W (SKU 114993346), direct to Pi 4 |
| Seeed Studio ReSpeaker USB mic array | 1 | XMOS XVF3800 DSP, onboard |

---

### Day 20 — The Final AI Control Station

| Item | Qty | Spec |
|---|---|---|
| ZoMa Brain LED ring | 1 | SparkFun LuMini 2" ring, 40× APA102 LEDs, driven from the Pi's hardware SPI — shows listening / thinking / speaking |
| Bulk capacitor at the ring's power pads | 1 | 470 µF |
| 5 V 5A buck converter for the ring | 1 | Separate from the Pi's own supply |
| 3D-printed ring bracket | 1 | 5–8 mm lip for an optional diffuser |

💡 **Why APA102 instead of WS2812 on the Pi.** WS2812 LEDs need a single data line with microsecond-exact timing, which a Linux computer can't guarantee while it's busy with other work. APA102 uses a separate clock line (SPI), so small timing hiccups don't corrupt the colors. It also dims smoothly and flickers less on camera.

💡 **Budget the current.** Each LED can draw up to ~60 mA at full white, so 40 LEDs could pull ~2.4 A. Either size the supply for that or cap the brightness in software.

---

## Reserved for Season 2 (not needed for the 20-day build)

| Item | Notes |
|---|---|
| ROS 2 + Nav2 (autonomous navigation) | Full SLAM/Nav2 stack — lidar-only ICP mapping and path planning. This build's Pi and server software stops at streaming, voice, and conversational AI |
| RPLIDAR C1 | Required for the planned lidar-only SLAM. UBEC branch installed on Day 3; mast slots cut on Day 1 |
| New mast with arm | Replaces the current mast |
| 16-channel PWM servo driver board | For the arm; deck space and a dedicated power branch are already reserved |
| Second battery | Same footprint as the first; deck space already reserved |

---

*ZoMa is property of TheMechanics. Contact: mamau.mechanics@gmail.com*

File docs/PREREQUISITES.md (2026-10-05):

# Prerequisites — Building ZoMa

ZoMa is a real robot, built by hand, with real hardware and real code. You don't need to be an expert to follow along, but you do need a few foundations. Here's an honest picture of what helps, in three tiers.

## Bring these with you

- **Working with AI on a project.** This build is developed with an AI partner, from brainstorming to deployment — including writing and adapting code for you if you can't do it yourself. You know how to give it clear context, ask for specific changes, and keep the project organized so it stays on track.
- **Clarity on what the code is doing.** You don't have to write a single line yourself. You do need to understand what each part does and why, well enough to check it, question it, and steer it.
- **Git basics.** Clone, commit, push, pull. The whole project lives in a repository, and so does your copy.
- **A troubleshooting mindset.** Things will go wrong: a wire in the wrong place, a voltage that's off, code that does nothing. You can change one thing at a time, re-test, and keep notes.
- **Patience with small steps.** Precision matters here. A rushed connection costs more time than a careful one.

## Helpful, and learnable along the way

Not required on day one. Each of these is shown on camera.

- Basic scripting and coding (variables, loops, functions, conditionals) —
  useful for following along, but not required: your AI partner can write
  and explain the code for you.
- Soldering and reading a multimeter
- Basic electronics: voltage, current, ground
- Comfort with a terminal and the command line
- Reading a wiring diagram

## You'll pick up in this series

You don't need any of this beforehand.

- Microcontrollers (ESP32) and motor drivers
- Power regulation and noise protection
- Sensor calibration: encoders and orientation
- Wireless links between boards
- The foundations of robot autonomy (ROS2 arrives in Season 2)

## Tools and time

- **Tools:** see the [equipment list](EQUIPMENT.md).
- **Time:** the full build is 20 days.

## The one thing that matters most

Curiosity and persistence. If you're willing to debug and to keep asking why, you can build this.

---

*ZoMa is property of TheMechanics. Contact: mamau.mechanics@gmail.com*

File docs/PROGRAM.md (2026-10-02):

# Building ZoMa: The Program

20 build days. 13 episodes. One robot, built from a flat sheet of acrylic.

Some episodes cover two or three build days in a single video. Day numbers always follow the build calendar. See [EQUIPMENT.md](EQUIPMENT.md) for the parts and tools needed on each day.

## Chapter 1: The Body (Days 1-7)

### Episode 1, Day 1: Building the Physical Skeleton
**Watch:** `TODO-URL`

Hand-cut acrylic with a ruler and a blade, no laser or CNC. Assemble the two-deck chassis and raise the vertical mast that becomes ZoMa's spine. No electronics yet.

### Episode 2, Day 2: Giving the Robot Wheels
**Watch:** `TODO-URL`

Install the drive motors, the rear wheels, and the front omniwheel. Then run the first raw spin test on the bench, before any brain and before any code.

### Episode 3, Day 3: The Power Problem
**Watch:** `TODO-URL`

Move from the cutting mat to the soldering station. Build a power distribution system with a capacitor bank and buck converters so every downstream chip gets clean power.

### Episode 4, Day 4: Bringing the Microchip to Life
**Watch:** `TODO-URL`

Mount the ESP32 microcontroller, tune its power, and run the first firmware. One blinking LED means the brain stem works.

### Episode 5, Day 5: Connecting Brain to Wheels
**Watch:** `TODO-URL`

Install the DRV8833 motor driver, wire motor control from the ESP32, and read encoder feedback for the first time.

### Episode 6, Days 6-7: Straight, and Exactly How Far
**Watch:** `TODO-URL`

Trim-tune the two rear motors until ZoMa drives dead straight. Then calibrate the encoders across measured floor runs so distance is accurate to the millimeter.

## Chapter 2: The Nervous System (Days 8-13)

### Episode 7, Day 8: Linking a PlayStation Controller
**Watch:** `TODO-URL`

Build a hand-made wireless transmitter and pair a PS5 DualSense controller to it over Bluetooth for manual control.

### Episode 8, Days 9-10: Cutting the Cord, and Taking the Wheel
**Watch:** `TODO-URL`

Establish a fast ESP-NOW radio link between the transmitter and the robot. Then translate joystick input into wheel commands and take ZoMa on its first manual drive, on the bench and across the floor.

### Episode 9, Days 11-12: A Sense of Direction
**Watch:** `TODO-URL`

Mount a BNO055 orientation sensor and watch live heading data stream in. Then use it for heading lock and exact turns, the difference between a robot that moves and one that navigates.

### Episode 10, Day 13: Installing the Onboard Computer and Eyes
**Watch:** `TODO-URL`

Assemble the top deck, mount the Raspberry Pi 4, and secure the camera on the mast.

## Chapter 3: The Mind (Days 14-20)

### Episode 11, Days 14-16: From Streaming Eyes to a Thinking Mind
**Watch:** `TODO-URL`

Stream live video from the robot, connect it to a local language model running on an off-board GPU, and have the first real-time conversation. Then let it describe what its camera sees.

### Episode 12, Days 17-19: Teaching ZoMa to Talk, and to Listen
**Watch:** `TODO-URL`

Add a speaker and text-to-speech so ZoMa can answer out loud. Then add a microphone and speech-to-text for fully hands-free, spoken conversation.

### Episode 13, Day 20: The Final AI Control Station
**Watch:** `TODO-URL`

Combine live video, sensor telemetry, and voice interaction into a single dashboard, and add an LED ring that shows when ZoMa is listening, thinking, or replying.

## Day-by-day reference

Checkpoints below are derived from the facts already in [EQUIPMENT.md](EQUIPMENT.md) and [WIRE_CONNECTIONS.md](WIRE_CONNECTIONS.md) — not independent specs. Where a day has no matching `WIRE_CONNECTIONS.md` section, none is listed (no wiring table exists for it yet — see the AI Build Partner's report on this for VL53L1X on Days 9–10, which `EQUIPMENT.md` lists as a part but `WIRE_CONNECTIONS.md` doesn't yet have a pin table for).

| Day | Episode | Scope | Done when | Repo material | Docs sections |
|---|---|---|---|---|---|
| 1 | Ep 1 | Hand-cut chassis, two decks, mast, cutouts. No electronics. | Both decks and the mast are assembled, cutouts made, structure is solid. | `mechanical/`, `mechanical/3d_design/` | EQUIPMENT Day 1 |
| 2 | Ep 2 | Drive motors, rear wheels, front omniwheel, first bench spin test. | Both motors spin the wheels on the bench supply; base is level. | `mechanical/` | EQUIPMENT Day 2 |
| 3 | Ep 3 | Battery, switch, WAGO distribution, capacitor bank, buck converters. | Every rail is measured with a multimeter at the right voltage before anything is connected to it. | — | EQUIPMENT Day 3 |
| 4 | Ep 4 | Mount the ESP32, tune its buck, flash first firmware. | The ESP32 runs on its regulated 5 V rail and the test LED blinks. | `esp32_rx/` | EQUIPMENT Day 4, SETUP §2 |
| 5 | Ep 5 | DRV8833 motor driver, motor control from the ESP32, first encoder readings. | The ESP32 drives the motors and encoder ticks are read. | `esp32_rx/` | EQUIPMENT Day 5, WIRE_CONNECTIONS (DRV8833 Motor Driver; Encoders) |
| 6 | Ep 6 (part 1) | Trim-tune the rear motors for a dead-straight drive. | The robot follows the floor tape line straight. | `esp32_rx/` | EQUIPMENT Day 6 |
| 7 | Ep 6 (part 2) | Calibrate encoders over measured floor runs. | You have your own ticks-per-mm number from real floor runs. | `esp32_rx/` | EQUIPMENT Day 7 |
| 8 | Ep 7 | Build the TX transmitter, pair a PS5 DualSense over Bluetooth. | The DualSense pairs with the TX ESP32. | `esp32_tx/`, `mechanical/3d_design/` (TX case) | EQUIPMENT Day 8, WIRE_CONNECTIONS (ESP32 TX Handheld Remote) |
| 9 | Ep 8 (part 1) | ESP-NOW radio link TX → RX. | TX and RX talk over ESP-NOW. | `esp32_tx/`, `esp32_rx/` | EQUIPMENT Days 9–10 |
| 10 | Ep 8 (part 2) | Joystick → wheel commands, first manual drives. | You drive ZoMa with the controller. | `esp32_tx/`, `esp32_rx/` | EQUIPMENT Days 9–10 |
| 11 | Ep 9 (part 1) | Mount the BNO055 orientation sensor, stream live heading. | Live heading data streams in. | `esp32_rx/` | EQUIPMENT Days 11–12, WIRE_CONNECTIONS (IMU BNO055) |
| 12 | Ep 9 (part 2) | Heading lock and exact turns. | The robot holds heading and turns by exact angles. | `esp32_rx/` | EQUIPMENT Days 11–12, WIRE_CONNECTIONS (IMU BNO055) |
| 13 | Ep 10 | Top deck, Raspberry Pi 4, camera on the mast. | Pi boots, camera is secured, data-only USB link to the ESP32 is in. | `pi/`, `pi/mediamtx.yml` | EQUIPMENT Day 13, SETUP §3, STARTUP_GUIDE §1.0–1.2, WIRE_CONNECTIONS (ESP32 RX ↔ Raspberry Pi 4 micro-ROS link) |
| 14 | Ep 11 (part 1) | Live video streaming from the robot. | Video from the robot shows on another machine. | `pi/mediamtx.yml`, `monster/zoma-brain/vision_stream.py` | EQUIPMENT Days 14–16, STARTUP_GUIDE §1.2 |
| 15 | Ep 11 (part 2) | Connect to a local LLM on the off-board GPU machine. | First real-time text conversation works. | `monster/zoma-brain/llm_engine.py`, `monster/zoma-brain/zoma_brain_server.py` | EQUIPMENT Days 14–16, STARTUP_GUIDE §2.2–2.3 |
| 16 | Ep 11 (part 3) | Vision: ZoMa describes what its camera sees. | ZoMa describes a live scene. | `monster/zoma-brain/vision_engine.py` | EQUIPMENT Days 14–16 |
| 17 | Ep 12 (part 1) | Speaker and text-to-speech. | ZoMa answers out loud. | `pi/scripts/zoma-audio-led/zoma_audio_client.py`, `monster/zoma-brain/tts_engine.py` | EQUIPMENT Days 17–19, WIRE_CONNECTIONS (Audio Subsystem), STARTUP_GUIDE §2.1 |
| 18 | Ep 12 (part 2) | Microphone array and speech-to-text. | ZoMa transcribes your voice. | `pi/scripts/zoma-audio-led/zoma_mic_client.py`, `monster/zoma-brain/zoma_brain_server.py` | EQUIPMENT Days 17–19, WIRE_CONNECTIONS (Audio Subsystem) |
| 19 | Ep 12 (part 3) | Fully hands-free spoken conversation. | A full voice conversation works. | `monster/zoma-brain/zoma_brain_server.py` | EQUIPMENT Days 17–19 |
| 20 | Ep 13 | Single dashboard (video, telemetry, voice) + LED ring status. | Dashboard works and the LED ring shows listening / thinking / speaking. | `web/index.html`, `pi/scripts/zoma-audio-led/zoma_state.py`, `pi/scripts/zoma-audio-led/lumini_ring.py` | EQUIPMENT Day 20, WIRE_CONNECTIONS (Status LED Ring APA102) |

## What comes next

Season 2 takes ZoMa from obeying commands to navigating on its own: mapping, planning, and driving autonomously with ROS2.

## Follow along

The full build is released as a video series on [TheMechanics-Lab on YouTube](https://www.youtube.com/@TheMechanics-Lab) — the series is collected in [this playlist](https://www.youtube.com/playlist?list=PLYKqW37Mjvkg).

---

*ZoMa is property of TheMechanics. Contact: mamau.mechanics@gmail.com*

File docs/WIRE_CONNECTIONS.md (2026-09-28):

# ZoMa — Wire Connections (Quick Reference)

Flat pinout/wiring lookup table for the whole build. See
[ARCHITECTURE.md](ARCHITECTURE.md) for the rationale behind each connection.

---

## ESP32 RX ↔ Raspberry Pi 4 (micro-ROS link)

The RX board's onboard USB port connects to the Raspberry Pi with a **data-only**
USB cable (the cable's power wire is cut, so the Pi doesn't also try to power the
board). micro-ROS runs over this USB-serial connection at 921600 baud — no separate
GPIO wiring is needed for this link.

---

## IMU (BNO055, I2C) ↔ ESP32 RX

| BNO055 Pin | ESP32 Pin | Wire Color | Notes |
| --- | --- | --- | --- |
| Vin | 3V3 | Red | Sensor logic power (3.3V) |
| GND | GND | Black | Common ground |
| SDA | GPIO21 | Green | I2C data line |
| SCL | GPIO22 | Yellow | I2C clock line |

---

## DRV8833 Motor Driver

### Logic Control Inputs (ESP32 RX → DRV8833)

| ESP32 RX GPIO | DRV8833 Pin | Function |
| --- | --- | --- |
| GPIO27 | IN1 | Right motor, PWM channel 1 |
| GPIO26 | IN2 | Right motor, PWM channel 2 |
| GPIO32 | IN3 | Left motor, PWM channel 1 |
| GPIO33 | IN4 | Left motor, PWM channel 2 |
| GND | GND | Shared ground reference (also carries LM2596 #1 OUT−)  |

*PWM: 5 kHz, 8-bit resolution, one LEDC channel per IN pin (4 channels total).*

### Power & Jumper Connections

| Source | Wire Color | DRV8833 Pin | Note |
| --- | --- | --- | --- |
| LM2596 #1 (motor rail) OUT+ | Red | VCC | Single combined pin — powers logic AND motor outputs |
| LM2596 #1 (motor rail) OUT− | Black | GND | Common ground — also receives ESP32 GND |

- `nSLEEP`: tied high via the board's on-board J1 jumper to VCC (not GPIO-controlled).
- `nFAULT`: left unconnected.

### Motor Outputs (DRV8833 → Motors)

| Motor | Wire | Color | DRV8833 Pin |
| ----- | ---- | ----- | --- |
| Right | M1 | Red | OUT1 |
| Right | M2 | White | OUT2 |
| Left  | M1 | Red | OUT3 |
| Left  | M2 | White | OUT4 |

---

## Encoders

### Motor-Side Wiring

| Motor Pin | Wire Color (Actual) | Function |
| --- | --- | --- |
| M1 | Red | Motor drive power (to DRV8833 OUT) |
| GND | Black | Encoder ground reference |
| C2 | Yellow | Encoder phase B signal |
| C1 | Green | Encoder phase A signal |
| VCC | Blue | Encoder logic power (3.3V / 5V) |
| M2 | White | Motor drive power (to DRV8833 OUT) |

### ESP32 RX Wiring — Encoder (Hardware Pulse Counters)

| Motor | Wire | ESP32 GPIO | Hardware Counter Unit |
| ----- | --- | --- | --- |
| Right | C1 (Green)  | GPIO35 | Counter unit 0, channel A (input-only pin)  |
| Right | C2 (Yellow) | GPIO34 | Counter unit 0, channel B (input-only pin)  |
| Left  | C1 (Green)  | GPIO18 | Counter unit 1, channel A |
| Left  | C2 (Yellow) | GPIO19 | Counter unit 1, channel B |

Encoders use hardware quadrature (x4) decoding — real A/B phase outputs give
direction natively, without needing to infer direction from commanded motor sign.

---

## ESP32 TX (Handheld Remote)

- **MCU:** ESP32 DevKit (Micro-USB, external IPEX/U.FL antenna connector)
- **Connectivity:** PS5 DualSense pairing over Bluetooth Classic; drive/telemetry
  link to ESP32 RX over ESP-NOW.

### Hardware & Power Components

- **Battery:** 3.7V 1000mAh 603048 LiPo (2-wire)
- **Charger:** TP4056 Type-C USB 5V 1A Li-ion charge controller with dual protection
- **Boost Converter:** DC-DC step-up converter (3.7V to 5V)
- **Status Ring:** WS2812B 5V addressable RGB LED ring, 12 LEDs, 16 mm diameter

### Power Distribution & Wiring

| Source | Destination | Wire Color | Function / Note |
| --- | --- | --- | --- |
| Battery (+) | TP4056 B+ | Red | Battery positive input |
| Battery (−) | TP4056 B− | Black | Battery negative input |
| TP4056 OUT+ | Boost IN+ | Red | Protected battery rail (via power switch) |
| TP4056 OUT− | Boost IN− | Black | Common circuit ground reference |
| Boost OUT+ (5V)  | ESP32 5V (VIN) | Red | 5V system supply rail |
| Boost OUT+ (5V)  | WS2812B 5V | Red | 5V power rail for LED ring |
| Boost OUT− (GND) | ESP32 GND | Black | Common ground |
| Boost OUT− (GND) | WS2812B GND | Black | Common ground |

### Status LED Ring Wiring

| WS2812B Pin  | ESP32 Pin | In-Line Component | Wire Color | Notes |
| --- | --- | --- | --- | --- |
| DI (Data In) | GPIO32 | 220Ω Resistor | Green / White | In-line damping resistor on data line |
| 5V | Boost OUT+ (5V) | — | Red | Dedicated 5V power tap |
| GND | Common GND | — | Black | Signal & power return path |

GPIO32 was chosen because it's not a strapping pin, not UART0, and not input-only.

---

## Audio Subsystem (Pi 4 ↔ ReSpeaker XVF3800 ↔ Mono Speaker)

- **Host Controller:** Raspberry Pi 4
- **Voice & Audio Interface:** Seeed Studio ReSpeaker USB (XMOS XVF3800 DSP array)
- **Speaker Transducer:** Seeed Studio Mono Enclosed Speaker — 4Ω 5W (SKU: 114993346)

### Interconnects & Signal Path

| From | To | Interface / Cable | Notes |
| --- | --- | --- | --- |
| Raspberry Pi 4 | ReSpeaker XVF3800  | USB-C to USB-A Cable | USB UAC 2.0 digital audio input/output, AEC reference, and bus power |
| ReSpeaker XVF3800 (SPK Out) | Seeed Mono Speaker | 2-pin JST (~400 mm)  | On-board Class-D audio amplifier output to mono enclosed speaker |

### Speaker Hardware Specifications (Seeed 114993346)

- **Rated Impedance:** 4Ω ± 15%
- **Power Handling:** 5W rated (6W peak / max)
- **Frequency Range:** ~450 Hz (Fo ± 20%) to 20 kHz
- **Termination:** ~400 mm lead terminated with 2-pin JST connector

### Mechanical & Mounting Dimensions

- **Overall Footprint (L × W × H):** 70.0 mm × 31.0 mm × 16.0 mm
- **Mounting Hole Spacing (Pitch):** 63.5 mm (lengthwise center-to-center) ×
  24.5 mm (widthwise center-to-center)
- **Mounting Hole Diameter:** ~3.2 mm (clearance for standard M3 screws)

---

## Status LED Ring (APA102) ↔ Raspberry Pi 4 / 5A Buck

- **Controller / Bus:** Raspberry Pi 4 hardware SPI0 (`GPIO10` / `GPIO11`)
- **Power Source:** 5V 5A buck converter (direct parallel tap, shared with Pi 4)
- **Buffering:** 470µF electrolytic capacitor across the ring's 5V and GND pads

### Wiring Details

| Ring Pin | Connected To | Wire Color | Function / Notes |
| --- | --- | --- | --- |
| **5V** | 5A Buck OUT+ | Red | 5V rail tap; 470µF cap (+) leg placed across 5V/GND |
| **GND**  | 5A Buck OUT− | Black | Common power return; 470µF cap (−) leg placed across 5V/GND |
| **DI** | Pi 4 GPIO 10 (Pin 19)  | Green | SPI0_MOSI (direct connection, 3.3V logic) |
| **CI** | Pi 4 GPIO 11 (Pin 23)  | Yellow | SPI0_SCLK (direct connection, 3.3V clock) |

---

## RPLIDAR C1 ↔ Raspberry Pi 4 / UBEC 5V

*Planned wiring for the lidar unit — part of the Season 2 autonomous navigation
work (see [ARCHITECTURE.md](ARCHITECTURE.md#4-planned--autonomous-navigation-season-2)),
not installed in this build. The UBEC power branch is already wired; the lidar
unit itself is not.*

- **Interface:** Pi 4 hardware primary UART (`/dev/ttyAMA0` or `/dev/serial0`)
- **Logic Level:** 3.3V TTL compatible
- **Power Source:** Dedicated 5V UBEC (direct parallel connection)

### Wiring Details

| RPLIDAR C1 Wire / Pin | Connected To | Wire Color | Function / Notes |
| --- | --- | --- | --- |
| **VCC (5V)** | UBEC 5V OUT+ | Red | Motor & core logic power (draws up to ~1.5A surge) |
| **GND** | UBEC 5V OUT− & Pi GND | Black | Shared common ground tied directly to UBEC OUT− and Pi 4 GND (e.g. Pin 6/9/14) |
| **TX** | Pi 4 GPIO 15 (Pin 10 / RXD0) | Green | LIDAR serial data out → Pi 4 UART receive |
| **RX** | Pi 4 GPIO 14 (Pin 8 / TXD0)  | Yellow | Pi 4 UART transmit → LIDAR command in |
| **MOTOCTR** (if present) | Pi 4 GPIO or 3V3/GND | — | Motor PWM speed control / enable (high or float to run) |

> A common ground jumper links the **UBEC OUT−** rail directly to a **Raspberry Pi 4
> GND pin** (Pin 6, 9, 14, 20, or 25), providing the reference return path for the
> GPIO 14/15 UART serial stream.

---

*ZoMa is property of TheMechanics. Contact: mamau.mechanics@gmail.com*

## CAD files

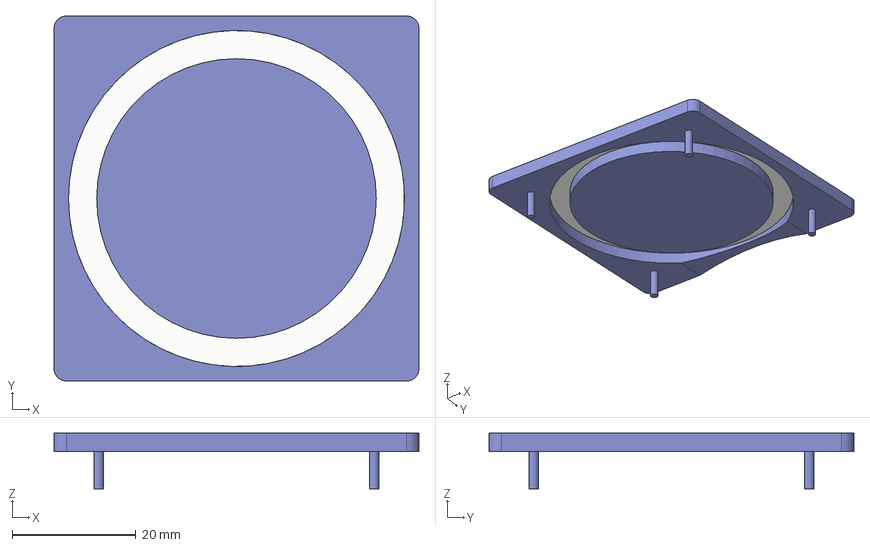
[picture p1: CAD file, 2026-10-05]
mechanical/3d_design/LED_Ring_Case/LED_Ring_Cover_v008.step
59.0 x 59.0 x 9.00 mm

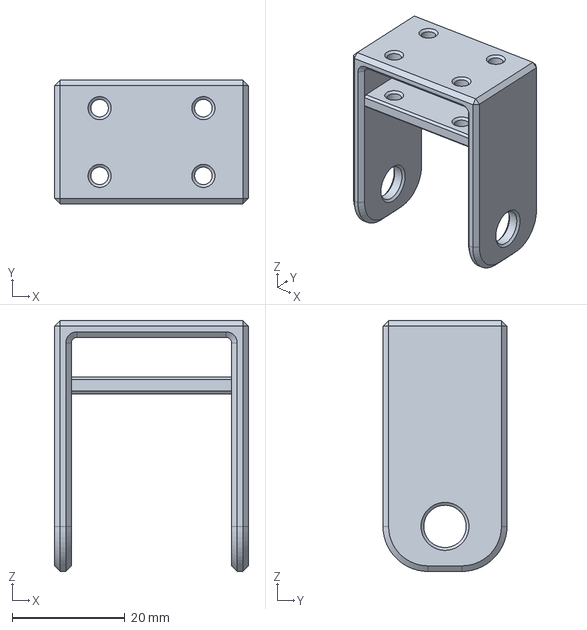
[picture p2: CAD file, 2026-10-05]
mechanical/3d_design/Omni_Wheel_Support_v001.step
34.4 x 22.0 x 44.5 mm

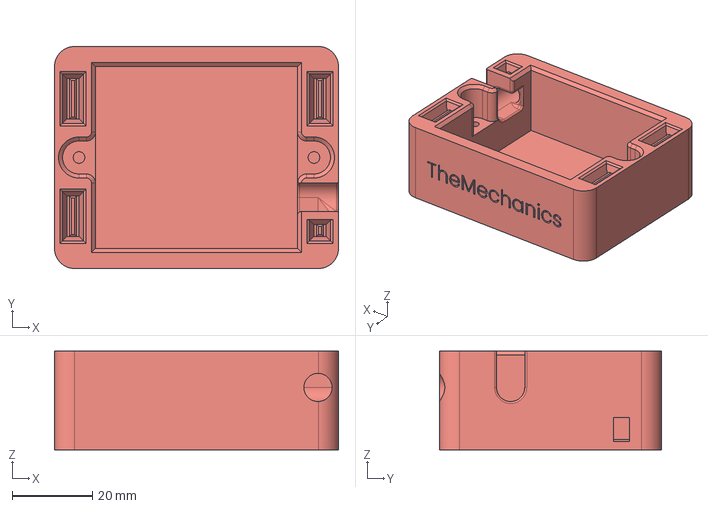
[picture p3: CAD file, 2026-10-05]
mechanical/3d_design/Speaker_Case/Speaker_Case_v002.step
70.6 x 55.2 x 24.5 mm

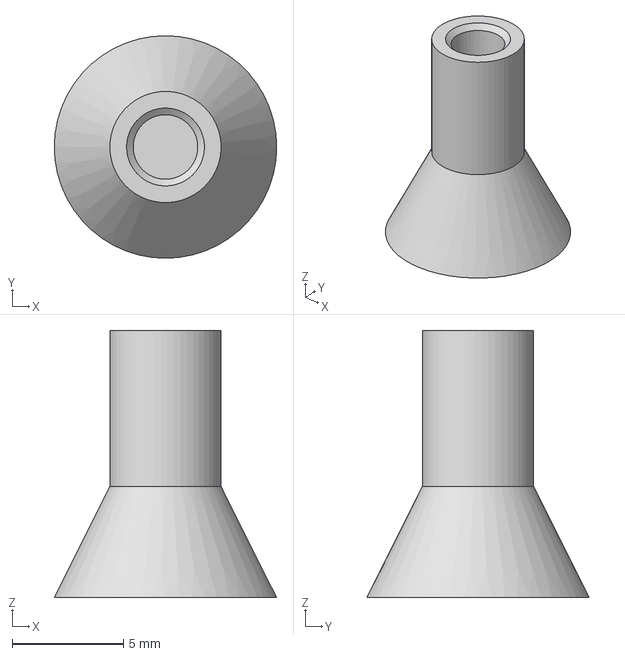
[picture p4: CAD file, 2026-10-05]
mechanical/3d_design/Standoff/Standoff_2.9mm_v001.step
10.0 x 10.0 x 12.0 mm

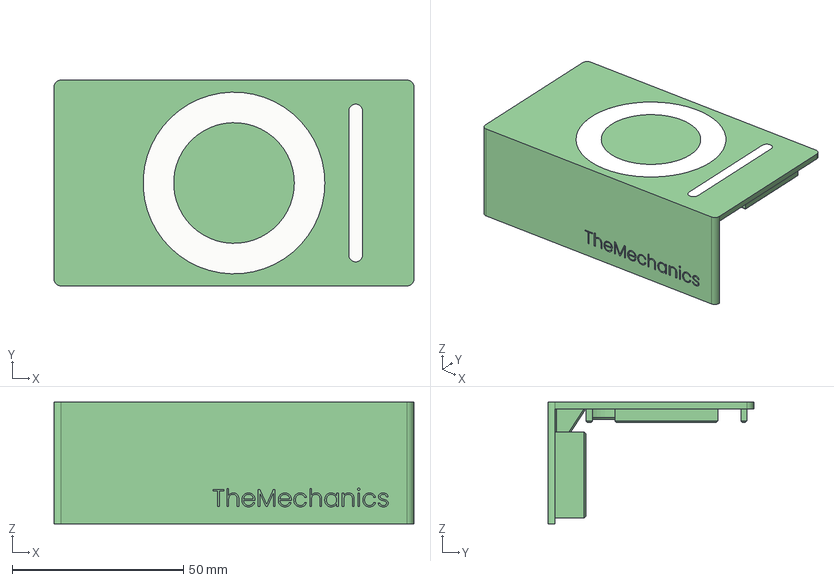
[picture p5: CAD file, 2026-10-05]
mechanical/3d_design/Transmitter_Box/Transmitter_Box_Cover_v007.step
105.0 x 60.0 x 35.5 mm

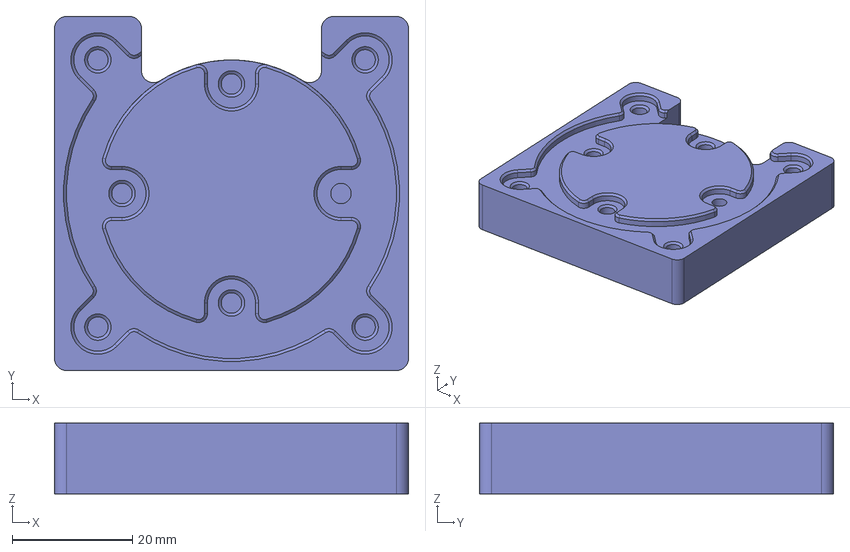
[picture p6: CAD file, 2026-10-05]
mechanical/3d_design/LED_Ring_Case/LED_Ring_Case_v008.step
59.0 x 59.0 x 11.8 mm

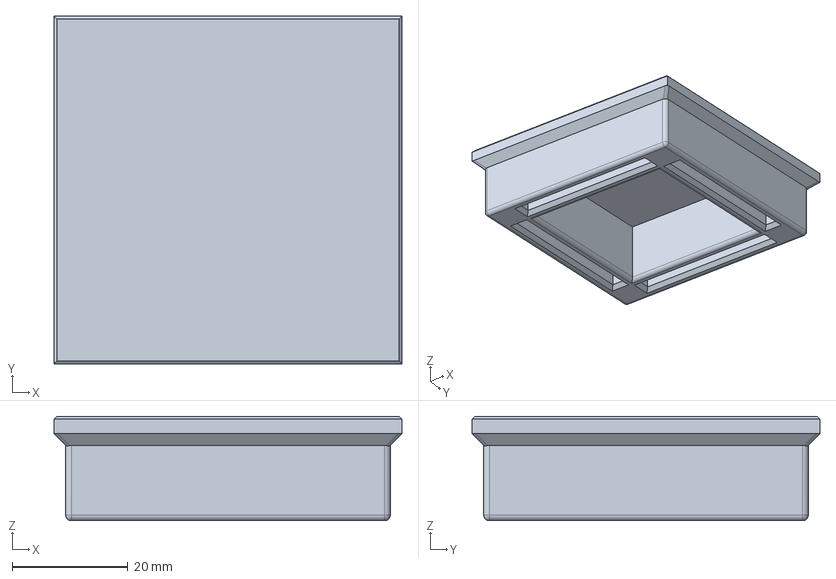
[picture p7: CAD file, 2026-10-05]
mechanical/3d_design/Mast/Mast_Top_v001.step
60.0 x 60.0 x 18.0 mm

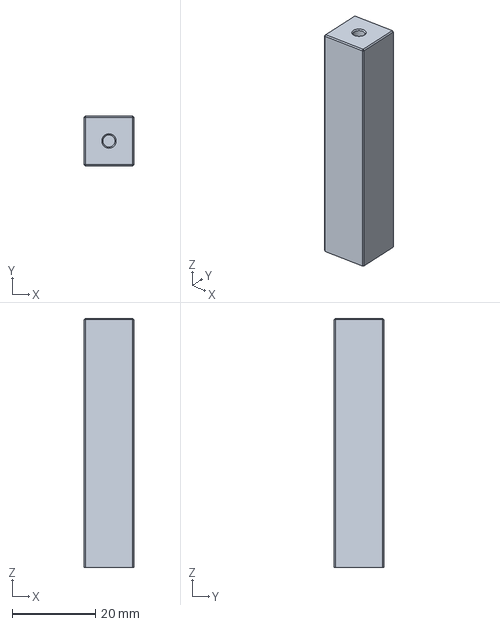
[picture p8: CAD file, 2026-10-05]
mechanical/3d_design/Pillar_v001.step
12.0 x 12.0 x 60.0 mm

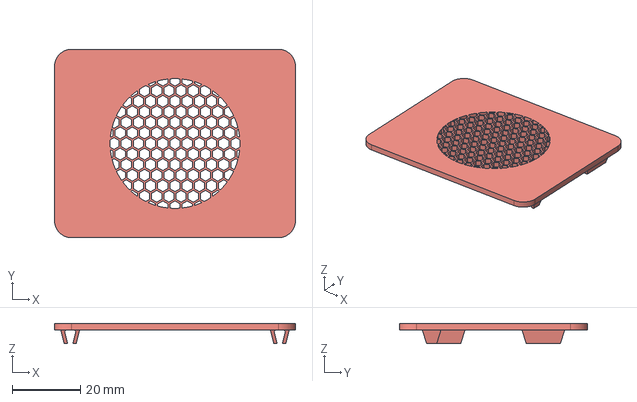
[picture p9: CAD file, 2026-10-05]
mechanical/3d_design/Speaker_Case/Speaker_Case_Cover_v002.step
70.6 x 55.2 x 6.00 mm

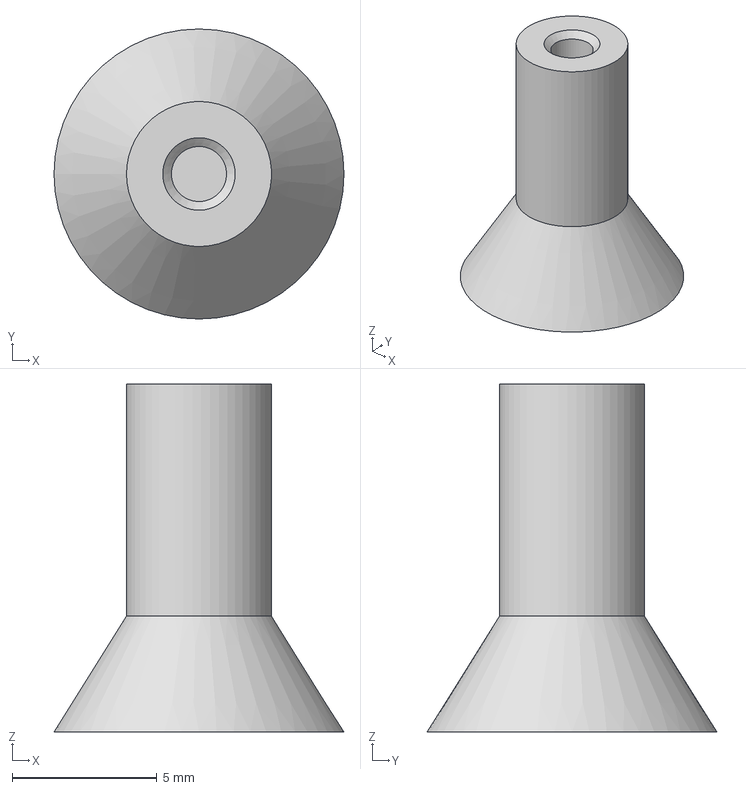
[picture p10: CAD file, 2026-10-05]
mechanical/3d_design/Standoff/Standoff_1.9mm_v001.step
10.0 x 10.0 x 12.0 mm

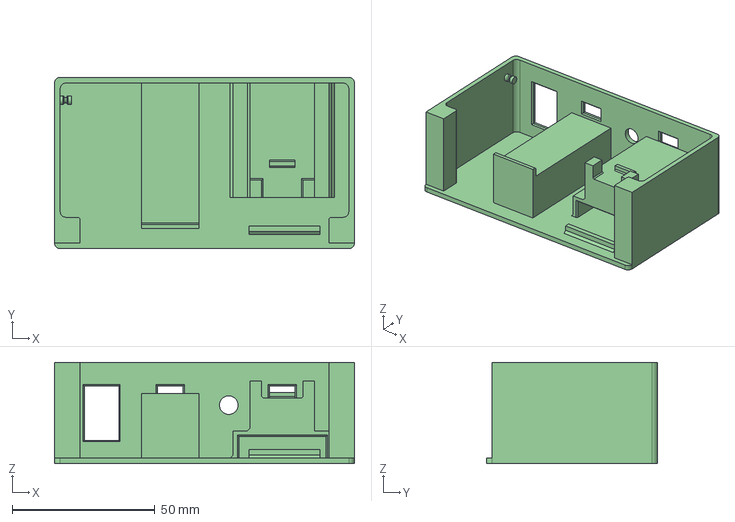
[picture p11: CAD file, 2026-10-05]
mechanical/3d_design/Transmitter_Box/Transmitter_Box_v004.step
105.0 x 60.0 x 35.5 mm

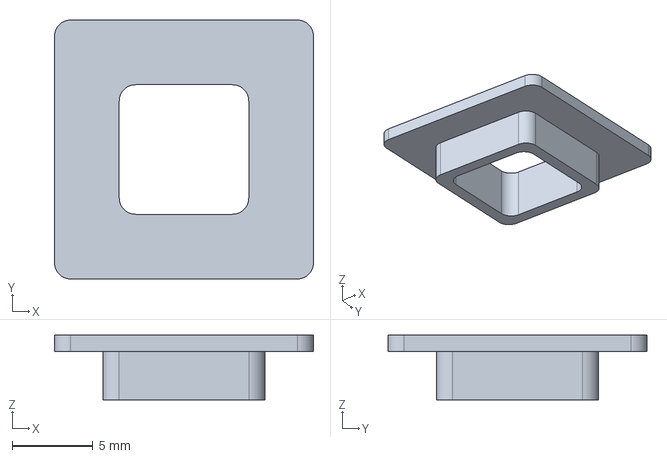
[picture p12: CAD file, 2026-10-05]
mechanical/3d_design/Frame_Motor_Wires_v001.step
16.0 x 16.0 x 4.00 mm

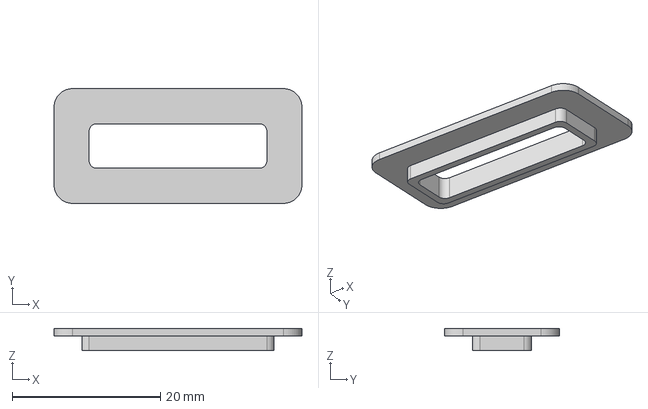
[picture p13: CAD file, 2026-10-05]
mechanical/3d_design/Mast/Mast_Frame_Small_v003.step
33.5 x 15.5 x 3.00 mm

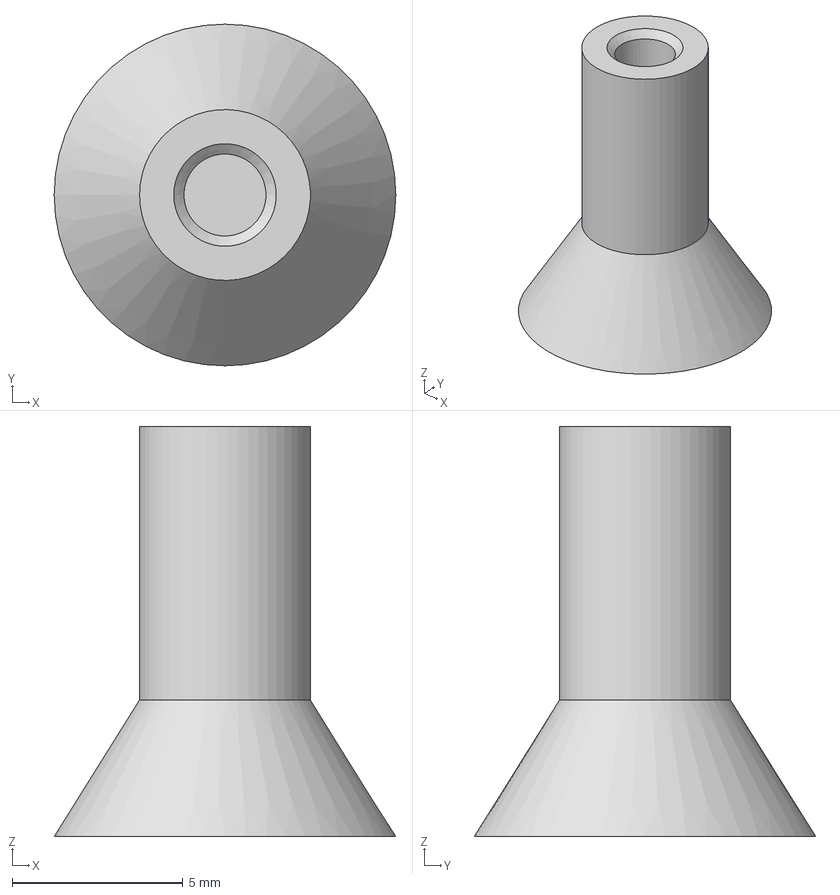
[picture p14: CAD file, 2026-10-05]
mechanical/3d_design/Standoff/Standoff_2.4mm_v001.step
10.0 x 10.0 x 12.0 mm

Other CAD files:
mechanical/3d_design/Mast/Mast_Base_v001.step
mechanical/3d_design/WiFi_Holder_v001.step
mechanical/3d_design/DRV8833_Platform_v001.step
mechanical/3d_design/Mast/Mast_Frame_Small_Flat_v004.step
mechanical/3d_design/Battery_Case_v002.step
mechanical/3d_design/Mast/Mast_Frame_Big_v003.step
mechanical/3d_design/Mast/Mast_Frame_Big_v004.step
mechanical/3d_design/Switch_Frame_v001.step

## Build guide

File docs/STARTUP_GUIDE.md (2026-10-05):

# ZoMa — Startup Guide

How to bring the whole system up: the Raspberry Pi's OS setup, ROS 2
container, camera stream, and audio/LED processes, then the off-board GPU
machine's (**Monster** — see [ARCHITECTURE.md](ARCHITECTURE.md)) Kokoro TTS
service and the ZoMa Brain server itself, and finally the web dashboard.
Start the Pi first, then Monster — ZoMa Brain connects out to the Pi's
camera stream on startup.

---

## 1. Raspberry Pi

### 1.0 Base OS setup

- Flash **Raspberry Pi OS (64-bit)** onto the microSD card with the
  [Raspberry Pi Imager](https://www.raspberrypi.com/software/) — use its
  "Edit Settings" step to set a hostname (`rb1` throughout this repo's
  examples), enable SSH, and configure Wi-Fi, so the Pi is reachable headless
  on first boot.
- Enable the camera, I2C, and SPI interfaces. **SPI is off by default** and
  is needed for the LuMini LED ring's `spidev` driver (§1.3):
  ```bash
  sudo raspi-config
  # Interface Options -> Camera -> Enable
  # Interface Options -> I2C     -> Enable
  # Interface Options -> SPI     -> Enable
  sudo reboot
  ```
- Install Docker (needed for the ROS 2 container below):
  ```bash
  curl -fsSL https://get.docker.com | sh
  sudo usermod -aG docker $USER   # log out/in for this to take effect
  ```

### 1.1 ROS 2 container (`zoma_ros_pi_v2`)

The Pi runs a single long-lived Docker container providing ROS 2 Humble — it
hosts the micro-ROS agent that bridges `esp32_rx`'s `deploy_ros` firmware to
the rest of the system, and it's where the `-hud` diagnostics scripts (§1.3)
run, since `rclpy` isn't installed on the Pi host directly.

[`pi/docker/Dockerfile`](../pi/docker/Dockerfile) builds a container with the
same runtime characteristics as the one this build actually runs
(reconstructed against the live container's `docker inspect` output, not the
original Dockerfile — if you have your own, use it instead):

```bash
docker build -t zoma_ros_pi_v2 pi/docker/
docker run -d --name zoma_ros_pi_v2 \
  --privileged \
  --network host \
  --restart always \
  -v /dev:/dev \
  -v ~/zoma_nav_ws:/zoma_nav_ws \
  zoma_ros_pi_v2
```

- `--privileged` + `-v /dev:/dev` — device access for the micro-ROS agent
  (the RX board's USB-serial connection) and other host devices as needed.
- `--network host` — required for ROS 2's DDS discovery to work correctly
  between the container and the rest of the Pi.
- `-v ~/zoma_nav_ws:/zoma_nav_ws` — an empty workspace directory, bind-mounted
  so ROS 2 packages can be developed without rebuilding the image. Empty for
  now; this is where Season 2's Nav2 packages will eventually live.
- The container's entrypoint keeps it running (`tail -f /dev/null`) rather
  than running a single foreground process — `start_zoma_audio_hud_pi.sh`
  `docker cp`'s a script in and `docker exec`'s it there on demand, instead
  of the container doing anything on its own.

### 1.2 Camera stream (MediaMTX)

The camera feed is served by [MediaMTX](https://github.com/bluenviron/mediamtx)
(a standalone media server) running on the Pi, republishing the Pi camera as
both RTSP (for ZoMa Brain's vision pipeline) and WebRTC (for the web
dashboard's live feed), using MediaMTX's built-in Raspberry Pi Camera source
— no separate `rpicam-vid`/`ffmpeg` piping needed. MediaMTX itself isn't part
of this repo — it's a general-purpose open-source tool, installed directly on
the Pi.

**Install:**

```bash
# On the Pi (aarch64):
curl -LO https://github.com/bluenviron/mediamtx/releases/latest/download/mediamtx_linux_arm64v8.tar.gz
tar -xzf mediamtx_linux_arm64v8.tar.gz
sudo mv mediamtx /usr/local/bin/
```

**Configure:** use [`pi/mediamtx.yml`](../pi/mediamtx.yml) — MediaMTX's
standard default config with one path defined, at the ports ZoMa Brain and
the web dashboard already expect by default (RTSP `8554`, WebRTC `8889`):

```yaml
paths:
  cam:
    source: rpiCamera
    rpiCameraWidth: 1920
    rpiCameraHeight: 1080
    rpiCameraFPS: 30
    rpiCameraBitrate: 4500000
    rpiCameraCodec: hardwareH264
    rpiCameraHDR: false
    rpiCameraShutter: 8000
    rpiCameraMetering: centre
    rpiCameraEV: 0.5
    rpiCameraDenoise: "cdn_off"
```

**Run:**

```bash
mediamtx /path/to/pi/mediamtx.yml
```

Set this up as a systemd service so it starts at boot. Verify it's working
before moving on:

```bash
ffplay rtsp://<pi-host>:8554/cam       # RTSP, from another machine
# or open http://<pi-host>:8889/cam/ in a browser for the WebRTC view
```

### 1.3 Audio, mic, and LED status scripts

These are the scripts in [`pi/scripts/zoma-audio-led/`](../pi/scripts/zoma-audio-led/):
`zoma_audio_client.py` (plays ZoMa Brain's TTS output), `zoma_mic_client.py`
(streams the mic to ZoMa Brain), and `zoma_state.py` (drives the LuMini LED
ring based on ZoMa Brain's state).

**Prerequisites:**

```bash
pip install websockets spidev
```

`websockets` is used by all three clients; `spidev` is needed by
`zoma_state.py` (via `lumini_ring.py`) to drive the LuMini ring over the Pi's
hardware SPI. `arecord`/`aplay` (ALSA utilities) are used for mic capture and
TTS playback — install with `sudo apt install alsa-utils` if not already
present. If you're using the ReSpeaker XVF3800 mic array, install its vendor
SDK (the `xvf_host` binary that `respeaker/xvf_init.sh` calls) from Seeed
Studio's own SDK repository, and point `RESPEAKER_SDK_DIR` at it (see below).

**Point the scripts at your ZoMa Brain server**, and (optionally) at wherever
you clone this repo and the ReSpeaker SDK on your Pi:

```bash
export ZOMA_BRAIN_HOST=<your Monster machine's LAN address>
export ZOMA_REPO_DIR=$HOME/ZoMa-V2-Public          # optional, defaults shown
export ZOMA_AUDIO_STATE_DIR=$HOME/zoma-audio        # optional, logs/PIDs
export RESPEAKER_SDK_DIR=$HOME/reSpeaker_XVF3800_USB_4MIC_ARRAY/host_control/rpi_64bit  # optional
```

**Start:**

```bash
cd pi/scripts/zoma-audio-led
./start_zoma_audio_hud_pi.sh          # audio + mic + LED ring
./start_zoma_audio_hud_pi.sh -hud     # also starts wifi/audio HUD diagnostics
                                       # (requires rclpy — see below)
```

Logs land in `$ZOMA_AUDIO_STATE_DIR/logs/`; tail the current day's file to
watch startup.

**Stop:**

```bash
./stop_zoma_audio_hud_pi.sh
```

**The `-hud` flag** runs `wifi_diag_publisher.py` and `audio_diag_publisher.py`
as ROS 2 nodes (they need `rclpy`, which isn't installed on the Pi host
directly) inside the `zoma_ros_pi_v2` container (§1.1) — start that container
first if you want `-hud` diagnostics.

**ReSpeaker recovery:** if mic capture wedges (repeated fast `arecord`
failures), `zoma_mic_client.py`'s recovery path calls
`reset_respeaker.sh`, which reboots the XVF3800's onboard DSP firmware via
`respeaker/xvf_init.sh`. Run `xvf_init.sh` once manually after first setting
up the mic array, and wire it into a systemd unit that runs at boot, before
the audio/LED scripts start.

### 1.4 Enrolling a voice for speaker ID

ZoMa Brain's speaker ID matches incoming mic audio against a "voice gallery"
of short recordings — `monster/zoma-brain/data/voice_gallery/*.wav` on
Monster. Record with the same mic the robot actually uses — accuracy depends
on matching the real microphone, not a phone or laptop mic — directly on the
Pi:

```bash
sudo apt install -y sox

# ~8s of normal speech, using the ReSpeaker mic array:
arecord -D plughw:CARD=Array,DEV=0 -f S16_LE -r 16000 -c 2 -t wav -d 8 raw_take1.wav

# Trim leading/trailing silence, normalize volume, and down-mix to mono:
sox raw_take1.wav -c 1 Alex_take1.wav norm silence 1 0.1 1% reverse silence 1 0.1 1% reverse
```

Record a few takes per person (`Alex_take1.wav`, `Alex_take2.wav`, ...) —
`zoma_brain_server.py`'s `init_speaker_id()` groups every `.wav` file by the
part of its filename before the first underscore, and averages all of a
person's takes into one profile. The exact sample rate/channel count of the
source recording doesn't matter beyond this — every gallery file is
auto-converted to mono/16kHz on load — but the filename prefix is what
identifies the person.

Copy the finished files into `monster/zoma-brain/data/voice_gallery/` on
Monster (they're gitignored there — personal recordings are never
committed), then (re)start `zoma_brain_server.py` to pick them up.

---

## 2. Monster (off-board GPU machine)

### 2.1 Kokoro TTS service

ZoMa Brain's text-to-speech runs as a separate local HTTP service — a
Docker container wrapping the open-weights [Kokoro-82M](https://huggingface.co/hexgrad/Kokoro-82M)
model — rather than being built into `zoma_brain_server.py`. This service
itself isn't part of this repo (it's generic, reusable infrastructure, kept
and versioned separately on Monster at `~/kokoro-service/`); what's documented
here is the contract `tts_engine.py` expects from it, so you can stand up a
compatible one.

**API contract** (what `tts_engine.py` calls):

- `POST /synthesize` — JSON body `{"text": str, "voice": str, "lang_code": str, "speed": float}`,
  returns the raw WAV audio bytes. One [`KPipeline`](https://github.com/hexgrad/kokoro)
  per `lang_code`, built lazily on first use, so the service can serve every
  language ZoMa Brain supports (`eng`/`it`/`fr`/`esp`) without a restart.
- `GET /health` — returns 200 once the service is ready.

**Minimal setup**, if you're building your own from scratch:

```bash
pip install kokoro torch fastapi uvicorn
```

Wrap `KPipeline(lang_code=...)` (from the `kokoro` package) in a small FastAPI
app exposing the two endpoints above, keeping a dict of pipelines keyed by
`lang_code` so each is only built once. Dockerize it with GPU passthrough and
build/run it as `kokoro-service`, listening on `127.0.0.1:8770` (the default
`KOKORO_SERVICE_URL` in `config.py`).

**Once built**, Kokoro runs inside Docker and starts automatically at boot
(`--restart unless-stopped`):

```bash
# Start the container (if stopped)
docker start kokoro-service

# View live logs
docker logs -f kokoro-service

# Check health
curl http://127.0.0.1:8770/health

# Rebuild and run (if Kokoro is down or unresponsive)
cd ~/kokoro-service
docker stop kokoro-service && docker rm kokoro-service
docker build -t kokoro-service .
docker run -d --name kokoro-service \
  --restart unless-stopped \
  --gpus all \
  -p 127.0.0.1:8770:8770 \
  kokoro-service
```

### 2.2 Ollama + Qwen models

ZoMa Brain's local (Tier 1) inference and its vision-language analysis run
through [Ollama](https://ollama.com), talked to over plain HTTP — not a pip
package, so it isn't in `requirements.txt`. Install it and pull the two
models ZoMa Brain expects by default:

```bash
curl -fsSL https://ollama.com/install.sh | sh

ollama pull qwen3:14b        # text model (config.QWEN_TEXT_MODEL)
ollama pull qwen2.5vl:7b     # vision-language model (config.QWEN_VL_MODEL)
```

Ollama starts its own local API server automatically on
`http://localhost:11434`. Override either model via the `QWEN_TEXT_MODEL` /
`QWEN_VL_MODEL` environment variables if you'd rather run different model
sizes for your GPU.

### 2.3 ZoMa Brain server

**Install the Python dependencies:**

```bash
cd monster/zoma-brain/
pip install -r requirements.txt
```

`torch`/`torchaudio` pull in a CPU-only build by default on some platforms —
if `torch.cuda.is_available()` comes back `False` after installing, reinstall
from PyTorch's CUDA index instead, e.g.:

```bash
pip install torch torchaudio --index-url https://download.pytorch.org/whl/cu121
```

**Prerequisites:**

- **NVIDIA CUDA GPU available** — Whisper initializes with `device="cuda"` by
  default (no CPU fallback), and Tier 1 local inference (Qwen via Ollama)
  needs it too. Running ZoMa fully GPU-free — targeting Claude for every
  query instead of local Qwen, and making Whisper's device configurable —
  isn't implemented in this build; see
  [ARCHITECTURE.md](ARCHITECTURE.md#3-software-stack). No GPU, and building
  with the [ZoMa AI Partner](../ZOMA_AI_PARTNER.md)? Ask it to help you adapt
  the code for this.
- **Ollama running**, with the Qwen models pulled — see §2.2 above.
- **Kokoro TTS running** — verify with `curl http://127.0.0.1:8770/health`
  (see §2.1 above).
- **The Pi's camera stream running** — see §1.1 above.
- **Environment variables**:
  - `ANTHROPIC_API_KEY` — required for Claude uplink sessions (warns if missing).
  - `HF_TOKEN` — required for speaker diarization/ID (speaker ID disables itself
    with a warning if unset).
- **System prompt file** — the target prompt file (e.g. `clorian_prompt.txt`) must
  exist relative to `monster/zoma-brain/`.

**Starting the server:**

Activate your Python environment and move into the server directory:

```bash
source /path/to/your/venv/bin/activate
cd /path/to/ZoMa-V2-Public/monster/zoma-brain/
```

### English (default)

```bash
python zoma_brain_server.py --name Clorian --prompt clorian_prompt.txt --lang eng --tts-voice am_adam
```

### Italian

```bash
python zoma_brain_server.py --name Clorian --prompt clorian_prompt.txt --lang it --tts-voice im_nicola --tts-speed 1.15
```

### French

```bash
python zoma_brain_server.py --name Clorian --prompt clorian_prompt.txt --lang fr --tts-voice ff_siwis --tts-speed 1.15
```

### Spanish

```bash
python zoma_brain_server.py --name Clorian --prompt clorian_prompt.txt --lang esp --tts-voice em_alex --tts-speed 1.15
```

---

## 3. Web dashboard

`web/index.html` is a static page — no build step, no server-side code.

1. Open it in a text editor and set the two `<YOUR_ZOMA_BRAIN_HOST>`
   placeholders (in the two `<script>` blocks) to Monster's LAN address — the
   same host `zoma_brain_server.py` is running on.
2. Serve the `web/` directory with a simple HTTP server — more reliable than
   opening the file directly, since the camera `<iframe>` can hit
   mixed-content restrictions when loaded from a bare `file://` page:
   ```bash
   cd web/
   python3 -m http.server 8000
   ```
3. Open `http://<any machine on your LAN>:8000/` in a browser. Both the Pi's
   camera stream (§1.2) and `zoma_brain_server.py` (§2.3) need to be running
   first.

---

## Parameter reference

| Flag | Type | Default | Description |
|---|---|---|---|
| `--name` | `str` | `Clorian` (`ZOMA_BRAIN_NAME`) | Assistant name; fallback for memory & wake-word |
| `--wake-word` | `str` | `--name` fallback | Spoken trigger keyword |
| `--memory-name` | `str` | `--name` fallback | Memory database slug to load |
| `--prompt` | `str` | `./clorian_prompt.txt` | System persona prompt file path |
| `--lang` | `choice` | `eng` (`eng`, `it`, `fr`, `esp`) | Active conversation language |
| `--reply-mode` | `choice` | `fixed` (`fixed`, `mirror`) | `fixed` locks to `--lang`; `mirror` matches speaker |
| `--stt-prompt` | `str` | Language table hint | Whisper bilingual initialization prompt |
| `--tts-voice` | `str` | Language default | Voice ID override for Kokoro TTS |
| `--tts-speed` | `float` | `1.0` | Voice playback speed multiplier |
| `--pi-host` | `str` | `rb1.local` (`ZOMA_PI_HOST`) | Raspberry Pi hostname or IP for the camera RTSP stream |
| `--pi-port` | `int` | `8554` | RTSP camera port (not the WebRTC port, 8889) |
| `--pi-path` | `str` | `cam` | RTSP stream endpoint path |
| `--no_vision` | `flag` | `off` | Disables camera ingestion and the vision pipeline |
| `--whisper_model` | `str` | `turbo` | Faster-Whisper model size |
| `--beam_size` | `int` | `10` | Whisper beam search width |
| `--port` | `int` | `8765` (`SERVER_PORT`) | WebSocket listening port |
| `--gallery_dir` | `str` | `./data/voice_gallery/` | Voice gallery directory for speaker ID |
| `--threshold` | `float` | `0.72` | Cosine similarity threshold for speaker ID |

---

## Additional examples

### Defaults only (Clorian, English, port 8765)

```bash
python zoma_brain_server.py
```

### Custom Pi RTSP host & tuned Italian persona

```bash
python zoma_brain_server.py --lang it --tts-voice im_nicola --tts-speed 0.9 \
  --pi-host rb1.local
```

### Secondary persona sharing Clorian's memory (no camera)

```bash
python zoma_brain_server.py --name Athena --wake-word computer \
  --memory-name Clorian --prompt ./athena_prompt.txt --no_vision
```

---

*ZoMa is property of TheMechanics. Contact: mamau.mechanics@gmail.com*

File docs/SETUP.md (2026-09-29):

# ZoMa — Setup

Repository layout and the development environment for each part of the build:
firmware, onboard Pi software, the off-board GPU machine, and the mechanical
chassis.

---

## 1. Repository layout

```
ZoMa-V2-Public/
├── docs/            # ARCHITECTURE.md, WIRE_CONNECTIONS.md, SETUP.md (this file), STARTUP_GUIDE.md, EQUIPMENT.md
├── esp32_tx/        # PS5 pairing + ESP-NOW to RX
├── esp32_rx/        # motors, IMU, encoders, micro-ROS client, e-stop
├── pi/              # ROS 2 container, MediaMTX config, ZoMa Brain audio/LED clients
├── monster/         # camera pipeline, ZoMa Brain (off-board GPU machine)
├── web/             # dashboard / web UI
└── mechanical/      # CAD/cut files for the chassis, and 3D-printable design files
```

Clone the full repository even if you're only working on one component — the docs
and cross-component wiring reference assume the whole tree is present.

Line endings are normalized to LF (`.gitattributes`: `* text=auto eol=lf`) so the
repo builds cleanly across Windows and macOS/Linux.

Secrets, Wi-Fi credentials, and any other machine-specific values are never
committed — see each component's section below for how they're supplied instead
(environment variables or a local, gitignored file).

## 2. Firmware build environment (ESP32 RX / TX)

- ESP32 RX firmware is built under WSL/Ubuntu on Windows machines — the
  `micro_ros_platformio` dependency build invokes colcon/meson via bash scripts
  that don't run natively on Windows. Builds work natively on macOS.
- `platformio.ini`'s `deploy_ros` environment is pinned to
  `platform = espressif32@6.5.0` — newer platform releases moved to an Arduino
  core that `micro_ros_platformio`'s build system doesn't support. Don't let a
  dependency update silently bump this.
- micro-ROS requires a baud rate of 921600.
- Each board ships a `debug_bench` environment (plain Serial output, no
  micro-ROS) and a `deploy_ros` environment (micro-ROS active, debug output
  compiled out). Prove a firmware change on `debug_bench` before flashing
  `deploy_ros`.
- `upload_port`/`monitor_port` are intentionally left unset in the committed
  `platformio.ini` files, so PlatformIO auto-detects the board. If you need to pin
  a specific port on your machine, set it in a local, gitignored
  `platformio.ini` override rather than committing one.

## 3. Onboard software (Raspberry Pi)

- Raspberry Pi OS (64-bit), with the camera, I2C, and SPI interfaces enabled
  via `raspi-config` (SPI is off by default and is needed for the LuMini LED
  ring). See [STARTUP_GUIDE.md](STARTUP_GUIDE.md#10-base-os-setup).
- ROS 2 Humble, run in Docker (`pi/docker/Dockerfile`) — runs the micro-ROS
  agent that bridges the RX board's `deploy_ros` firmware to the rest of the
  system, and hosts the `-hud` diagnostics scripts. See
  [STARTUP_GUIDE.md](STARTUP_GUIDE.md#11-ros-2-container-zoma_ros_pi_v2).
- [MediaMTX](https://github.com/bluenviron/mediamtx) serves the Pi camera as
  both RTSP (for ZoMa Brain's vision pipeline) and WebRTC (for the web
  dashboard) — not part of this repo, installed directly on the Pi and
  configured with [`pi/mediamtx.yml`](../pi/mediamtx.yml). See
  [STARTUP_GUIDE.md](STARTUP_GUIDE.md#12-camera-stream-mediamtx).
- Boot automation: a systemd service launches the onboard stack (micro-ROS agent,
  MediaMTX, audio/LED host processes) into a tmux session, so it's inspectable
  and restartable without re-running everything by hand.
- The scripts in `pi/scripts/` reference the repo's install location on the Pi
  through a variable near the top of each script — set that to wherever you clone
  this repo on your own Pi. See [STARTUP_GUIDE.md](STARTUP_GUIDE.md#13-audio-mic-and-led-status-scripts)
  for how to start them.
- EKF, a lidar driver, and Nav2 are part of the planned Season 2 autonomous
  navigation stack — not part of this build. See
  [ARCHITECTURE.md](ARCHITECTURE.md#4-planned--autonomous-navigation-season-2).

## 4. Off-board GPU machine — `monster/` (ZoMa Brain)

- Runs ZoMa Brain (local LLM + vision-language model serving, STT), decoding
  the Pi's RTSP camera stream rather than capturing video itself.
- Kokoro TTS runs as a separate Docker service Monster talks to over HTTP —
  see [STARTUP_GUIDE.md](STARTUP_GUIDE.md#21-kokoro-tts-service) for the API
  contract and how to stand it up.
- GPU passthrough (`--gpus all`) is required for any container touching the GPU.
- If running under WSL2: GStreamer pipelines relying on wall-clock timestamps can
  break due to WSL2 clock stepping — use a no-clock pipeline pattern
  (`buffer-mode=none ntp-sync=false` + `use_gst_timestamps:true`) if this comes up.
- API keys (e.g. `ANTHROPIC_API_KEY`) and other secrets are read from environment
  variables or a local file outside the repo — never hardcoded. See
  [STARTUP_GUIDE.md](STARTUP_GUIDE.md) for the exact variables ZoMa Brain expects.

## 5. Mechanical build

- 3 mm acrylic, 30×30 cm two-deck chassis with a vertical camera mast, hand-cut
  with a ruler and blade (no laser, no CNC).
- CAD/cut templates and 3D-printable design files live in `mechanical/` (see
  [`mechanical/3d_design/`](../mechanical/3d_design/) for printed parts).
- Battery placement (centered, bottom deck), the reserved second-battery
  footprint, and IMU isolation are mechanical constraints — factor them into any
  cut-layout changes, not just the electrical wiring. See
  [ARCHITECTURE.md](ARCHITECTURE.md) for the reasoning behind each of these.

## 6. Before you build

1. Read [ARCHITECTURE.md](ARCHITECTURE.md) and [WIRE_CONNECTIONS.md](WIRE_CONNECTIONS.md).
2. Check [EQUIPMENT.md](EQUIPMENT.md) for the parts and tools needed, organized
   by build day.
3. Build and prove each module in isolation (`debug_bench` for firmware, or the
   equivalent bench setup for other components) before integrating it into the
   full, deployed system.
4. Confirm physical assumptions (encoder counts-per-revolution, pin behavior,
   wiring) against your own hardware rather than trusting a datasheet alone — real
   builds vary.

---

*ZoMa is property of TheMechanics. Contact: mamau.mechanics@gmail.com*

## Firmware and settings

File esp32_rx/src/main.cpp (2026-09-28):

// ZoMa RX firmware — main entry point: drive mode + calibration/bench tests.
// Property of TheMechanics. Contact: mamau.mechanics@gmail.com
//
// Selects one of several build-time modes (drive mode or a numbered calibration
// test) via CAL_TEST, and implements each mode's setup()/loop().

#include <Arduino.h>
#include <Preferences.h>
#include <WiFi.h>
#include <math.h>

#include "bno055.h"
#include "debug_macros.h"
#include "encoders.h"
#include "espnow_rx.h"
#include "motors.h"
#include "pins.h"

// ============================================================================
// CALIBRATION MODE SELECT — override via a `-D CAL_TEST=n` PlatformIO build flag
// (see platformio.ini's cal_test_1..cal_test_5 environments), or leave unset for
// the default:
//   0 = DRIVE MODE (default, no flag needed) — ESP-NOW receive -> deadzone/sign/
//       e-stop processing -> arcade kinematics -> motors, running continuously.
//       debug_bench and deploy_ros both build with no CAL_TEST flag, so both
//       default to drive mode.
//   1 = CAL TEST 1: straight-line trim test (visual — tape line on the floor)
//   2 = CAL TEST 2: distance/encoder calibration (drive untethered, measure tape)
//   3 = CAL TEST 3: live encoder read, no motor drive
//   4 = bench test: forward/pause/reverse/pause, logging encoder deltas
//   5 = CAL TEST 5: BNO055 bring-up — live yaw/pitch/roll serial log, no motor
//       drive.
// ============================================================================
#ifndef CAL_TEST
#define CAL_TEST 0
#endif

namespace {


constexpr uint32_t SERIAL_BAUD = 115200;
constexpr int16_t TEST_DUTY = 210; // ~82% of 255, safe bench-test speed

// ---- Trim ----
// Independently scales each side's duty. Start 1.00 / 1.00 for the first Test 1 run.
// If the robot curves toward the right, the right side is under-driven relative to
// the left (or the left is over-driven) — nudge in ~0.02 steps and pick one
// convention (e.g. always correct the weaker side upward) so results stay comparable
// between attempts. Reflash after each change; log the final values once settled.
constexpr float RIGHT_TRIM = 1.00f;
constexpr float LEFT_TRIM  = 1.0097f;

constexpr uint32_t CAL_DRIVE_MS = 4000; // both cal tests: 4s drive, per the test plan

// Test 2 only: set true for exactly one flash to clear a previously saved result
// and force a fresh drive on next boot. Set back to false and reflash again before
// the real run — otherwise every subsequent reset re-clears and re-drives.
constexpr bool CAL2_FORCE_RESET = false;

int16_t trimmedDuty(int16_t base, float trim) {
  return static_cast<int16_t>(base * trim);
}

} // namespace

// ============================================================================
#if CAL_TEST == 1
// CAL TEST 1 — straight-line trim test
// ============================================================================
namespace {
uint32_t driveStartMs = 0;
bool stopped = false;
} // namespace

void setup() {
  DBG_BEGIN(SERIAL_BAUD);
  delay(200); // let the USB serial monitor attach before the first prints
  DBG_PRINTLN();
  DBG_PRINTLN("[ZoMa RX] CAL TEST 1 -- straight-line trim test");
  DBG_PRINTF("[CAL1] trims: right=%.2f left=%.2f  base duty=%d\n", RIGHT_TRIM, LEFT_TRIM, TEST_DUTY);
  DBG_PRINTLN("[CAL1] place robot on the tape line, drive starts immediately on boot/reset");

  motors::begin();

  driveStartMs = millis();
  motors::setRight(trimmedDuty(TEST_DUTY, RIGHT_TRIM));
  motors::setLeft(trimmedDuty(TEST_DUTY, LEFT_TRIM));
}

void loop() {
  if (!stopped && millis() - driveStartMs >= CAL_DRIVE_MS) {
    motors::stop();
    stopped = true;
    DBG_PRINTLN("[CAL1] done -- check drift against the tape line, adjust RIGHT_TRIM/LEFT_TRIM, reflash and repeat");
  }
}

// ============================================================================
// ============================================================================
#elif CAL_TEST == 2
// CAL TEST 2 -- distance / encoder calibration test
// ============================================================================
namespace {
Preferences prefs;
int32_t rStart = 0, lStart = 0;
int32_t savedRightTicks = 0, savedLeftTicks = 0;
bool driveDone = false;
uint32_t driveStartMs = 0;
uint32_t lastPrintMs = 0;

constexpr uint32_t PRE_DRIVE_DELAY_MS = 30000; // time to unplug USB and place the robot
} // namespace

void setup() {
  DBG_BEGIN(SERIAL_BAUD);
  delay(200);
  DBG_PRINTLN();
  DBG_PRINTLN("[ZoMa RX] CAL TEST 2 -- distance/encoder calibration");

  prefs.begin("cal2", false); // NVS namespace "cal2", read/write

  if (CAL2_FORCE_RESET) {
    prefs.clear();
    DBG_PRINTLN("[CAL2] CAL2_FORCE_RESET=true -- cleared saved result.");
    DBG_PRINTLN("[CAL2] Set CAL2_FORCE_RESET back to false and reflash before the drive will start on the next boot.");
    motors::begin(); // keep motors silenced
    driveDone = true; // do NOT drive on the same boot that clears -- stops here
    return;
  }

  bool haveSavedResult = prefs.getBool("done", false);

  if (haveSavedResult) {
    // A result from a previous untethered run is already on flash (it survives the
    // reset that happens when USB gets replugged) -- report it, don't drive again.
    savedRightTicks = prefs.getInt("rTicks", 0);
    savedLeftTicks = prefs.getInt("lTicks", 0);
    DBG_PRINTLN("[CAL2] found a saved result from a previous run -- reporting it, not driving again.");
    DBG_PRINTLN("[CAL2] to run a fresh test: set CAL2_FORCE_RESET=true, reflash once, then set it back to false and reflash again.");
    motors::begin();
    driveDone = true;
    return;
  }

  DBG_PRINTF("[CAL2] trims: right=%.2f left=%.2f  base duty=%d\n", RIGHT_TRIM, LEFT_TRIM, TEST_DUTY);
  DBG_PRINTF("[CAL2] %lu ms until drive starts -- unplug USB and place the robot now.\n",
             static_cast<unsigned long>(PRE_DRIVE_DELAY_MS));

  motors::begin();
  encoders::begin();

  // Countdown, printed once per second, while USB is still connected (or not --
  // this runs regardless, the prints just won't be seen if already unplugged).
  for (uint32_t remaining = PRE_DRIVE_DELAY_MS; remaining > 0; remaining -= 1000) {
    DBG_PRINTF("[CAL2] starting in %lu s...\n", static_cast<unsigned long>(remaining / 1000));
    delay(1000);
  }

  DBG_PRINTLN("[CAL2] mark start position now -- driving.");

  rStart = encoders::rightCount();
  lStart = encoders::leftCount();

  driveStartMs = millis();
  motors::setRight(trimmedDuty(TEST_DUTY, RIGHT_TRIM));
  motors::setLeft(trimmedDuty(TEST_DUTY, LEFT_TRIM));
}

void loop() {
  if (!driveDone) {
    if (millis() - driveStartMs >= CAL_DRIVE_MS) {
      motors::stop();

      int32_t rEnd = encoders::rightCount();
      int32_t lEnd = encoders::leftCount();
      savedRightTicks = rEnd - rStart;
      savedLeftTicks = lEnd - lStart;

      prefs.putInt("rTicks", savedRightTicks);
      prefs.putInt("lTicks", savedLeftTicks);
      prefs.putBool("done", true);

      driveDone = true;
      DBG_PRINTLN("[CAL2] drive complete, result saved to flash -- safe to replug USB now");
    }
    return;
  }

  if (millis() - lastPrintMs >= 1000) {
    lastPrintMs = millis();
    DBG_PRINTF("[CAL2 RESULT] right ticks=%ld  left ticks=%ld  -- measure tape distance (mm), divide by ticks for ticks/mm\n",
               static_cast<long>(savedRightTicks), static_cast<long>(savedLeftTicks));
  }
}
// ============================================================================

// ============================================================================
#elif CAL_TEST == 3
// CAL TEST 3 -- live encoder read, no motor drive. Spin a wheel by hand and
// watch the counts change in real time. Useful to confirm each encoder responds
// correctly, in the expected direction, before trusting a full drive test.
// ============================================================================
namespace {
uint32_t lastPrintMs = 0;
} // namespace

void setup() {
  DBG_BEGIN(SERIAL_BAUD);
  delay(200);
  DBG_PRINTLN();
  DBG_PRINTLN("[ZoMa RX] CAL TEST 3 -- live encoder read (no motor drive)");
  DBG_PRINTLN("[CAL3] spin a wheel by hand, watch counts change below");

  motors::begin(); // keeps motors silenced, no drive commanded
  encoders::begin();
}

void loop() {
  if (millis() - lastPrintMs >= 200) {
    lastPrintMs = millis();
    DBG_PRINTF("[CAL3] right=%ld  left=%ld\n",
               static_cast<long>(encoders::rightCount()),
               static_cast<long>(encoders::leftCount()));
  }
}

#elif CAL_TEST == 4
// CAL_TEST == 4 -- bench test: forward/pause/reverse/pause, logging encoder deltas
// ============================================================================
namespace {

constexpr uint32_t PHASE_DURATION_MS = 5000;
constexpr uint32_t PAUSE_DURATION_MS = 2000;
constexpr uint32_t LOG_INTERVAL_MS = 500;

enum class Phase { FORWARD, PAUSE1, REVERSE, PAUSE2, DONE };

Phase phase = Phase::FORWARD;
uint32_t phaseStartMs = 0;
uint32_t lastLogMs = 0;
int32_t rightAtPhaseStart = 0;
int32_t leftAtPhaseStart = 0;

const char* phaseName(Phase p) {
  switch (p) {
    case Phase::FORWARD: return "FORWARD";
    case Phase::PAUSE1: return "PAUSE";
    case Phase::REVERSE: return "REVERSE";
    case Phase::PAUSE2: return "PAUSE";
    case Phase::DONE: return "DONE";
  }
  return "?";
}

void enterPhase(Phase p) {
  phase = p;
  phaseStartMs = millis();
  rightAtPhaseStart = encoders::rightCount();
  leftAtPhaseStart = encoders::leftCount();

  switch (p) {
    case Phase::FORWARD:
      motors::setRight(TEST_DUTY);
      motors::setLeft(TEST_DUTY);
      break;
    case Phase::REVERSE:
      motors::setRight(-TEST_DUTY);
      motors::setLeft(-TEST_DUTY);
      break;
    case Phase::PAUSE1:
    case Phase::PAUSE2:
    case Phase::DONE:
      motors::stop();
      break;
  }

  DBG_PRINTLN();
  DBG_PRINTF("[ZoMa Brain RX] entering phase: %s\n", phaseName(p));
}

void logStatus() {
  int32_t right = encoders::rightCount();
  int32_t left = encoders::leftCount();
  DBG_PRINTF("[%s] t=%lums right=%ld (d=%ld) left=%ld (d=%ld)\n", phaseName(phase),
             static_cast<unsigned long>(millis() - phaseStartMs), static_cast<long>(right),
             static_cast<long>(right - rightAtPhaseStart), static_cast<long>(left),
             static_cast<long>(left - leftAtPhaseStart));
}

} // namespace

void setup() {
  DBG_BEGIN(SERIAL_BAUD);
  delay(200);
  DBG_PRINTLN("[ZoMa Brain RX] motor + encoder bench test starting");

  motors::begin();
  encoders::begin();

  enterPhase(Phase::FORWARD);
}

void loop() {
  uint32_t now = millis();
  uint32_t elapsed = now - phaseStartMs;

  if (phase != Phase::DONE && now - lastLogMs >= LOG_INTERVAL_MS) {
    logStatus();
    lastLogMs = now;
  }

  switch (phase) {
    case Phase::FORWARD:
      if (elapsed >= PHASE_DURATION_MS) enterPhase(Phase::PAUSE1);
      break;
    case Phase::PAUSE1:
      if (elapsed >= PAUSE_DURATION_MS) enterPhase(Phase::REVERSE);
      break;
    case Phase::REVERSE:
      if (elapsed >= PHASE_DURATION_MS) enterPhase(Phase::PAUSE2);
      break;
    case Phase::PAUSE2:
      if (elapsed >= PAUSE_DURATION_MS) enterPhase(Phase::DONE);
      break;
    case Phase::DONE:
      break;
  }
}

// ============================================================================
#elif CAL_TEST == 5
// CAL TEST 5 -- BNO055 bring-up: live yaw/pitch/roll serial log, no motor drive.
// Bench procedure: place ZoMa flat on the bench, confirm yaw/pitch/roll all read
// ~0, then turn it by hand ~90 degrees and confirm yaw tracks to ~90 (+/- a few
// degrees). IMUPLUS mode (see bno055.cpp) gives a RELATIVE heading, not a compass
// bearing, so yaw@boot is always ~0 by construction -- that's expected, not a
// coincidence.
// ============================================================================
void setup() {
  DBG_BEGIN(SERIAL_BAUD);
  delay(200);
  DBG_PRINTLN();
  DBG_PRINTLN("[ZoMa RX] CAL TEST 5 -- BNO055 bring-up (no motor drive)");

  motors::begin(); // keeps motors silenced, no drive commanded

  if (!bno055::begin()) {
    DBG_PRINTF("[CAL5] BNO055 not detected -- check wiring (VIN=3V3, GND, SDA=%d, SCL=%d)\n",
               pins::IMU_SDA, pins::IMU_SCL);
  } else {
    DBG_PRINTLN("[CAL5] BNO055 ready -- place flat, confirm ~0/0/0, then turn by hand");
  }
}

void loop() {
  bno055::update();
  bno055::log();
}

// ============================================================================
#else
// CAL_TEST == 0 -- DRIVE MODE (default)
//   ESP-NOW receive -> input arbitration -> arcade kinematics -> motors,
//   running continuously. Watchdog and e-stop override unconditionally.
//
// INPUT MODEL (GT7-style):
//   - Left stick: proportional throttle/steering.
//   - R2/L2: adaptive 0-100% power, forward (R2) / reverse (L2), independent
//     of D-pad state. Both engage heading-hold, latched to yaw at the moment
//     either trigger is first pressed -- same behavior as D-pad Up/Down.
//   - D-pad: fixed-magnitude crawl (DPAD_MAGNITUDE). Up/Down drive straight
//     with heading-hold latched to the yaw at the moment the button is first
//     pressed; Left/Right turn freely, not locked to any heading.
//   - Priority when multiple are active at once: stick > R2/L2 > D-pad. Only
//     one source drives the motors on any given tick.
//   - Safety interlock: if R2 and L2 are both pressed at the same time, ALL
//     trigger-driven power is withheld until at least one of them is fully
//     released (back to raw 0) -- not just back under its deadzone.
// ============================================================================
namespace {

using espnow_rx::ControlPacket;

constexpr int16_t STICK_DEADZONE = 8;
constexpr uint8_t TRIGGER_DEADZONE = 8; // same reasoning as STICK_DEADZONE, R2/L2 side

// Bench-tunable. TX sends at ~50Hz (20ms), so 300ms is ~15 missed packets before
// the watchdog trips -- generous margin against a single dropped frame, tight
// enough that a real link loss (TX powered off / out of range) stops the robot
// quickly. Re-tune on the bench if this feels too twitchy or too slow to react.
constexpr uint32_t RECEIVE_TIMEOUT_MS = 300;

constexpr uint32_t LOG_INTERVAL_MS = 200; // throttle serial so it doesn't flood

// E-stop buttons: Options or Share, either one alone trips it -- OR semantics,
// since requiring a precise simultaneous double-press is the wrong trade-off
// for a safety stop.
constexpr uint32_t ESTOP_BUTTON_MASK = espnow_rx::BTN_OPTIONS | espnow_rx::BTN_SHARE;

int16_t applyDeadzone(int16_t value) {
  return (abs(value) < STICK_DEADZONE) ? 0 : value;
}
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
void loop() {
  ControlPacket packet;
  if (espnow_rx::getLatestPacket(packet)) {
    lastKnownPacket = packet;
    haveKnownPacket = true;
  }

  // Feeds bno055::yawDegrees() for heading-hold below. Single minimal I2C
  // transaction, rate-limited internally to ~50Hz -- see bno055.cpp/.h for why
  // this must stay the only sensor read on this fast path.
  bno055::update();

  bool linkUp = haveKnownPacket && espnow_rx::msSinceLastPacket() <= RECEIVE_TIMEOUT_MS;

  int16_t rawThrottle = 0;
  int16_t rawSteering = 0;
  int16_t throttle = 0;
  int16_t steering = 0;
  bool estopActive = false;
  const char* source = "IDLE";

  if (linkUp) {
    rawThrottle = lastKnownPacket.throttle;
    rawSteering = lastKnownPacket.steering;

    int16_t filteredThrottle = applyDeadzone(rawThrottle);
    int16_t filteredSteering = applyDeadzone(rawSteering);
    bool stickActive = (filteredThrottle != 0) || (filteredSteering != 0);

    // Trigger interlock -- checked every tick regardless of which priority
    // branch ends up driving, so a stale block clears even while the stick or
    // D-pad is what's actually being used at the moment.
    bool r2Pressed = lastKnownPacket.r2 > TRIGGER_DEADZONE;
    bool l2Pressed = lastKnownPacket.l2 > TRIGGER_DEADZONE;
    if (lastKnownPacket.r2 == 0 || lastKnownPacket.l2 == 0) {
      triggersBlocked = false;
    }
    if (r2Pressed && l2Pressed) {
      triggersBlocked = true;
    }
    bool triggersActive = (r2Pressed || l2Pressed) && !triggersBlocked;

    bool dpadActive = (lastKnownPacket.buttons &
                        (espnow_rx::BTN_UP | espnow_rx::BTN_DOWN | espnow_rx::BTN_LEFT |
                         espnow_rx::BTN_RIGHT)) != 0;
    bool dpadForward = (lastKnownPacket.buttons & (espnow_rx::BTN_UP | espnow_rx::BTN_DOWN)) != 0;
    bool dpadTurning = (lastKnownPacket.buttons & (espnow_rx::BTN_LEFT | espnow_rx::BTN_RIGHT)) != 0;

    // ---- PRIORITY 1: left stick ----
    if (stickActive) {
      source = "STICK";
      // Throttle sign convention: positive = forward (REP-103-style, matching
      // the project's odometry work). The PS5 stick's Y axis reads negative
      // when pushed forward/up; TX sends it raw and un-negated (dumb pass-
      // through), so the negation happens here, once, at the RX boundary.
      throttle = static_cast<int16_t>(-filteredThrottle);
      // Steering sign not flipped -- independent of the throttle sign on this
      // wiring.
      steering = filteredSteering;
      headingHoldActive = false;

    // ---- PRIORITY 2: R2/L2 -- adaptive forward/reverse, GT7-style, with
    // heading-hold identical to D-pad Up/Down. ----
    } else if (triggersActive) {
      source = "TRIG";

      float currentYaw = bno055::yawDegrees();
      if (!headingHoldActive) {
        // Latches the instant R2 or L2 first crosses the deadzone -- releasing
        // and re-pressing re-targets to wherever the robot is now facing.
        headingHoldTargetYaw = currentYaw;
        headingHoldActive = true;
      }
      float error = angleError(headingHoldTargetYaw, currentYaw);
      // Deadband -- see HEADING_HOLD_DEADBAND_DEG's comment above. Correction
      // stays exactly 0 (not just small) inside the deadband.
      int16_t correction = 0;
      if (fabsf(error) > HEADING_HOLD_DEADBAND_DEG) {
        correction = static_cast<int16_t>(constrain(error * HEADING_HOLD_KP,
                                           (float)-HEADING_HOLD_MAX_CORRECTION,
                                           (float)HEADING_HOLD_MAX_CORRECTION));
      }
      steering = correction;

      if (r2Pressed) {
        // Sign matches D-pad's BTN_UP below -- both are "forward" through the
        // exact same mixAndDrive(), so they share the same empirical sign.
        throttle = -triggerMagnitude(lastKnownPacket.r2);
      } else { // l2Pressed
        throttle =  triggerMagnitude(lastKnownPacket.l2);
      }

      // Rate-limited diagnostic print of heading-hold tracking while R2/L2 drive.
      static uint32_t lastHoldDebugMsTrig = 0;
      if (millis() - lastHoldDebugMsTrig > 150) {
        lastHoldDebugMsTrig = millis();
        DBG_PRINTF("[HOLD-TRIG] target=%6.1f current=%6.1f error=%6.1f correction=%4d\n",
                   headingHoldTargetYaw, currentYaw, error, correction);
      }

    // ---- PRIORITY 3: D-pad -- fixed magnitude, heading-hold on straight. ----
    } else if (dpadActive) {
      source = "DPAD";
      throttle = 0;
      steering = 0;
      // BTN_UP/DOWN are net-negated once by mixAndDrive()'s internal
      // `-throttle` -- this sign is empirical, bench-confirmed.
      if (lastKnownPacket.buttons & espnow_rx::BTN_UP)    throttle = -DPAD_MAGNITUDE;
      if (lastKnownPacket.buttons & espnow_rx::BTN_DOWN)  throttle =  DPAD_MAGNITUDE;
      if (lastKnownPacket.buttons & espnow_rx::BTN_LEFT)  steering = -DPAD_MAGNITUDE;
      if (lastKnownPacket.buttons & espnow_rx::BTN_RIGHT) steering =  DPAD_MAGNITUDE;

      bool wantHeadingHold = dpadForward && !dpadTurning;
      if (wantHeadingHold) {
        float currentYaw = bno055::yawDegrees();
        if (!headingHoldActive) {
          // Latches the instant BTN_UP/BTN_DOWN is first pressed -- not a
          // fixed reference heading, so releasing and re-pressing the D-pad
          // re-targets to wherever the robot is now facing.
          headingHoldTargetYaw = currentYaw;
          headingHoldActive = true;
        }
        float error = angleError(headingHoldTargetYaw, currentYaw);
        int16_t correction = 0;
        if (fabsf(error) > HEADING_HOLD_DEADBAND_DEG) {
          correction = static_cast<int16_t>(constrain(error * HEADING_HOLD_KP,
                                             (float)-HEADING_HOLD_MAX_CORRECTION,
                                             (float)HEADING_HOLD_MAX_CORRECTION));
        }
        steering += correction;

        // Rate-limited diagnostic print of heading-hold tracking while D-pad drives.
        static uint32_t lastHoldDebugMs = 0;
        if (millis() - lastHoldDebugMs > 150) {
          lastHoldDebugMs = millis();
          DBG_PRINTF("[HOLD] target=%6.1f current=%6.1f error=%6.1f correction=%4d\n",
                     headingHoldTargetYaw, currentYaw, error, correction);
        }
      } else {
        headingHoldActive = false;
      }

    // ---- Nothing active. ----
    } else {
      headingHoldActive = false;
    }

    // RX-side e-stop check: TX no longer filters anything, so a held e-stop
    // combo in the received packet must independently zero all drive output
    // here, not just be trusted to have already been zeroed upstream.
    estopActive = (lastKnownPacket.buttons & ESTOP_BUTTON_MASK) != 0;
  } else {
    headingHoldActive = false;
  }

  // ---- Watchdog + e-stop: unconditional override, not a suggestion ----
  // No fresh packet within RECEIVE_TIMEOUT_MS, or the e-stop combo is held ->
  // motors::stop() every loop until a fresh, non-e-stopped packet arrives. When
  // the pad is centered and untouched this falls out naturally from the deadzone
  // + zero-throttle path above, but the watchdog/e-stop path here is what
  // guarantees it when the link itself is the problem.
  if (!linkUp || estopActive) {
    motors::stop();
    resetDriveRamp();
  } else {
    mixAndDrive(throttle, steering);
  }

  logDriveState(rawThrottle, rawSteering, throttle, steering, linkUp, source);

  delay(10);
}

#endif

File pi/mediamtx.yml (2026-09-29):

# ZoMa Pi -- MediaMTX config: publishes the Pi camera as RTSP (for ZoMa
# Brain's vision pipeline) and WebRTC (for the web dashboard's live feed).
# Property of TheMechanics. Contact: mamau.mechanics@gmail.com
#
# This is MediaMTX's own standard default configuration file, with one path
# ("cam") defined at the bottom using MediaMTX's built-in Raspberry Pi Camera
# source -- no separate rpicam-vid/ffmpeg piping needed. See
# docs/STARTUP_GUIDE.md for install and run instructions.

###############################################
# Global settings

# Settings in this section are applied anywhere.

###############################################
# Global settings -> General

# Verbosity of the program; available values are "error", "warn", "info", "debug".
logLevel: info
# Destinations of log messages; available values are "stdout", "file" and "syslog".
logDestinations: [stdout]
# When destination is "stdout" or "file", emit logs in structured format (JSONL).
logStructured: false
# When "file" is in logDestinations, this is the file which will receive logs.
logFile: mediamtx.log
# When "syslog" is in logDestinations, use prefix for logs.
sysLogPrefix: mediamtx
# Dump packets to disk. This is useful for debugging.
dumpPackets: false

# Timeout of read operations.
readTimeout: 10s
# Timeout of write operations.
writeTimeout: 10s
# Size of the queue of outgoing packets.
# A higher value allows to increase throughput, a lower value allows to save RAM.
writeQueueSize: 512
# Maximum size of outgoing UDP payloads.
# It defaults to the maximum packet size on ethernet (1500) minus IPv6 and UDP headers (48).
# This can be decreased to avoid fragmentation on networks with a low MTU.
udpMaxPayloadSize: 1452
# Size of the read buffer of every UDP socket.
# This can be increased to decrease packet losses.
# It defaults to the default value of the operating system.
udpReadBufferSize: 0

# Command to run when a client connects to the server.
# This is terminated with SIGINT when a client disconnects from the server.
# The following environment variables are available:
# * MTX_CONN_TYPE: connection type
# * MTX_CONN_ID: connection ID
# * RTSP_PORT: RTSP server port
runOnConnect:
# Restart the command if it exits.
runOnConnectRestart: false
# Command to run when a client disconnects from the server.
# Environment variables are the same as runOnConnect.
runOnDisconnect:

###############################################
# Global settings -> Authentication

# Authentication method. Available values:
# * Internal database: credentials are stored in the configuration file
# * External HTTP server: an external HTTP URL is contacted for each authentication request
# * External JWT provider: credentials are signed tokens released by an external identity server
authMethod: internal

# Internal authentication.
# Enabled users.
authInternalUsers:
  # Default unprivileged user.
  # Username. 'any' means any user, including anonymous ones.
  - user: any
    # Password. Not used in case of 'any' user.
    pass:
    # IPs or networks allowed to use this user. An empty list means any IP.
    ips: []
    # Permissions.
    permissions:
      # Available actions are: publish, read, playback, api, metrics, pprof.
      - action: publish
        # Paths can be set to further restrict access to a specific path.
        # An empty path means any path.
        # Regular expressions can be used by using a tilde as prefix.
        path:
      - action: read
        path:
      - action: playback
        path:

    # Default administrator.
    # This allows to use API, metrics and PPROF without authentication,
    # if the IP is localhost.
  - user: any
    pass:
    ips: ["127.0.0.1", "::1"]
    permissions:
      - action: api
      - action: metrics
      - action: pprof

# HTTP-based authentication.
# URL called to perform authentication. Every time a user wants
# to authenticate, the server calls this URL with the POST method
# and a payload described in the documentation.
# If the response code is 20x, authentication is accepted, otherwise
# it is discarded.
authHTTPAddress:
# If the HTTP authentication URL has a self-signed or invalid certificate,
# you can provide the fingerprint of the certificate in order to
# validate it anyway. It can be obtained by running:
# openssl s_client -connect auth_http_domain:443 </dev/null 2>/dev/null | sed -n '/BEGIN/,/END/p' > server.crt
# openssl x509 -in server.crt -noout -fingerprint -sha256 | cut -d "=" -f2 | tr -d ':'
authHTTPFingerprint:
# Actions to exclude from HTTP-based authentication.
# Format is the same as the one of user permissions.
authHTTPExclude:
  - action: api
  - action: metrics
  - action: pprof
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

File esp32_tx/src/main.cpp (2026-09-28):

// ZoMa TX firmware — entry point.
// Property of TheMechanics. Contact: mamau.mechanics@gmail.com
//
// Wires together PS5 pad input, the ESP-NOW drive link to the RX board, and
// the status LED ring, and runs the main transmit loop.

#include <Arduino.h>
#include <WiFi.h>

#include "espnow_tx.h"
#include "led_status.h"
#include "ps5_handler.h"

// Replace with your ESP32 RX board's MAC address (read it via
// WiFi.macAddress() on the RX board).
const uint8_t CAR_RECEIVER_MAC[] = {0x00, 0x00, 0x00, 0x00, 0x00, 0x00};

namespace {

// LED ring runs on its own FreeRTOS task, independent of loop()'s cadence --
// PS5 pad polling can block for multi-second stretches while searching for a
// connection, so tick() is driven from a dedicated task rather than from
// loop() to keep the ring animating smoothly regardless.
void ledTask(void*) {
  for (;;) {
    led_status::tick();
    vTaskDelay(pdMS_TO_TICKS(30)); // matches led_status's own frame interval
  }
}

// ESP-NOW link state is derived from sendControlPacket()'s own send result,
// debounced over a short window so a single dropped send doesn't flicker the
// ring. The main loop only sends while the pad is connected, so this
// correctly ages out to SEARCHING on its own once nothing has been sent
// successfully for a while.
constexpr uint32_t ESPNOW_UP_WINDOW_MS = 300;
bool everEspNowOk = false;
uint32_t lastEspNowOkMs = 0;

void noteEspNowSendResult(bool ok) {
  if (ok) {
    everEspNowOk = true;
    lastEspNowOkMs = millis();
  }
}

led_status::LinkState currentEspNowState() {
  if (!everEspNowOk) return led_status::LinkState::SEARCHING;
  return (millis() - lastEspNowOkMs) < ESPNOW_UP_WINDOW_MS ? led_status::LinkState::CONNECTED
                                                             : led_status::LinkState::SEARCHING;
}

} // namespace

void setup() {
  Serial.begin(115200);

  Serial.println("\n==========================================");
  Serial.println("   ESP32 CONTROLLER TRANSMITTER MODULE    ");
  Serial.println("==========================================");

  led_status::begin(); // ring starts on Status::BOOTING

  xTaskCreatePinnedToCore(ledTask, "led_ring", 4096, nullptr, 1, nullptr, 1);

  initPS5Controller();
  Serial.println("PS5 Bluetooth Subsystem Initialized.");

  WiFi.mode(WIFI_STA);
  Serial.print("This board's MAC: ");
  Serial.println(WiFi.macAddress());

  if (!initESPNowTransmitter(CAR_RECEIVER_MAC)) {
    Serial.println("Fatal: ESP-NOW failed to initialize!");
    led_status::set(led_status::Status::ERROR);
  }

  Serial.println("Waiting for PS5 Controller connection...");
}

void loop() {
  ControllerInput input = readPS5Controller();

  led_status::setBt(input.connected ? led_status::LinkState::CONNECTED
                                     : led_status::LinkState::SEARCHING);

  if (input.connected) {
    ControlPacket packet;
    packet.throttle = input.throttle;
    packet.steering = input.steering;
    packet.rx       = input.rx;
    packet.ry       = input.ry;
    packet.l2       = input.l2;
    packet.r2       = input.r2;
    packet.boost    = input.boost;
    packet.buttons  = input.buttons;

    sendControlPacket(packet);
    noteEspNowSendResult(lastSendWasAcked());

    Serial.printf("TX -> Thr:%4d Str:%4d | Rx:%4d Ry:%4d | L2:%3d R2:%3d | Boost:%d | Btns:0x%05lX\n",
                  packet.throttle, packet.steering,
                  packet.rx, packet.ry,
                  packet.l2, packet.r2,
                  packet.boost, (unsigned long)packet.buttons);

    led_status::setEspNow(currentEspNowState());

    vTaskDelay(pdMS_TO_TICKS(20)); // ~50Hz transmit loop
  } else {
    static unsigned long lastLog = 0;
    if (millis() - lastLog > 3000) {
      Serial.println("Waiting for PS5 Controller connection!!");
      lastLog = millis();
    }

    led_status::setEspNow(currentEspNowState());

    vTaskDelay(pdMS_TO_TICKS(100));
  }
}

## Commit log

2026-09-28 Add ZoMa firmware, backend, dashboard, and docs
    Public, sanitized copy of the ZoMa build: ESP32 RX/TX firmware, the
    Raspberry Pi audio/LED scripts, the ZoMa Brain AI backend, the web
    dashboard, and finalized architecture/wiring/setup/startup docs.
    Claude-Session: https://claude.ai/code/session_017MPXqgCNQobf7y56m2178B
2026-09-28 Add build-day equipment list and 3D design folder; clarify ROS/Nav2 as Season 2
    Publish docs/EQUIPMENT.md (parts and tools by build day). Add
    mechanical/3d_design/ for 3D-printable part designs (TX case, edge
    profiles, brackets). Correct README/ARCHITECTURE/SETUP/WIRE_CONNECTIONS
    to state that ROS 2, SLAM, Nav2, and the EKF/lidar stack are planned for
    a second build season and are not implemented in this build.
    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
2026-09-28 Turn EQUIPMENT.md into a plain bill of materials
    The build is complete and fully filmed, so drop the ✅/🟡/⚠️ build-status
    markers and legend — every item is just listed by day now, with any
    spec nuance folded into plain text instead of a status flag.
    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
2026-09-28 Add dual license, YouTube channel link, and fix ring LED spec
    Add LICENSE (CC BY-NC-SA 4.0 for hardware/CAD/docs, GPLv3 for
    software/firmware), link it from README, and add a YouTube channel
    reference (TheMechanics-Lab). Also correct the ZoMa Brain interaction
    ring spec in ARCHITECTURE.md/README.md: it's a 40-LED SparkFun LuMini
    (APA102) driven from the Pi's SPI, not the originally-planned 16-LED
    WS2812 ring -- that WS2812 ring is the separate TX remote's connection-
    status indicator.
    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
2026-09-28 Expand STARTUP_GUIDE.md: Pi camera/audio/LED startup, Kokoro install
    Add a Raspberry Pi section covering MediaMTX camera streaming (install,
    config, verify) and starting/stopping the audio/mic/LED status scripts,
    plus a Monster section documenting the Kokoro TTS service's API contract
    and how to build/run one, ahead of the existing ZoMa Brain server launch
    instructions. SETUP.md cross-references both.
    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
2026-09-28 Fill dependency gaps: numpy/huggingface_hub, Pi requirements.txt, Ollama docs
    monster/zoma-brain/requirements.txt was missing numpy and huggingface_hub,
    both imported directly rather than pulled in transitively. Add a
    requirements.txt for the Pi audio/LED scripts (websockets, spidev).
    Document Ollama installation and pulling the two Qwen models
    (qwen3:14b, qwen2.5vl:7b) in STARTUP_GUIDE.md -- it's talked to over
    plain HTTP, not a pip package, so it was previously just a one-line
    prerequisite bullet with no install instructions. Also note the
    CUDA-vs-CPU torch wheel gotcha.
    Claude-Session: https://claude.ai/code/session_017MPXqgCNQobf7y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
2026-09-28 Align EQUIPMENT.md component names with WIRE_CONNECTIONS.md
    Pull specific component names/specs from WIRE_CONNECTIONS.md into the
    equipment list wherever it was more generic: WS2812B ring (was
    "addressable RGB LED ring"), TP4056's 5V 1A/dual-protection spec, the
    TX LiPo's 1000mAh/603048 spec, the Seeed ReSpeaker XVF3800 mic array
    and Seeed Mono Speaker (was "USB speaker"/"microphone array"), RPLIDAR
    C1 (was "Lidar"), and the 220ohm inline resistor value. Also mark the
    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
2026-09-29 Clarify Qwen (local) vs Claude (uplink) inference and GPU requirement
    Tier 1 is local Qwen text/vision on Monster's GPU via Ollama; Tier 2 is
    Claude (Anthropic API) reached with a manual "start uplink" command --
    Claude also handles vision directly, confirmed by reading
    claude_engine.py's frame-attachment code. Documented that Whisper is
    separately hardcoded to device="cuda" with no CPU fallback, so running
    fully GPU-free (defaulting to Claude for everything, making Whisper's
    device configurable) would need a code change this build doesn't
    implement -- informational only, not built.
    Claude-Session: https://claude.ai/code/session_017MPX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
2026-09-29 Close four repo gaps: OS setup, ROS2 container, MediaMTX, voice enrollment
    - pi/docker/Dockerfile: reconstructed from `docker inspect` against the
    real zoma_ros_pi_v2 container (ROS 2 Humble, privileged, host network,
    /dev and a nav workspace bind-mounted) -- previously an empty
    placeholder with zero setup instructions anywhere in the repo.
    - pi/mediamtx.yml: the real MediaMTX config in use, showing the built-in
    rpiCamera source. Corrects STARTUP_GUIDE.md's prior description, which
    documented a manual rpicam-vid|ffmpeg pipe that isn't what actually
    runs.
    - STARTUP_GUIDE.md: new "1.0 Base OS setup" section (Raspberry Pi OS,
    raspi-config camera/I2C/SPI, Docker install) and "1.4 E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
    [mediamtx.yml]
2026-10-02 Add ZoMa AI Build Partner prompt + Claude Code auto-load
    ZOMA_AI_PARTNER.md: the day-by-day build coach prompt, added verbatim
    except for the Section 4 "Likely repo material" column, which is
    corrected against the real file tree (added missing EQUIPMENT.md day
    citations for Days 9-12, pointed Days 13-20 at the specific files that
    now exist rather than whole folders, and flagged mechanical/3d_design/
    as still empty pending the CAD/STL upload).
    CLAUDE.md: a single @import so Claude Code loads the coach
    automatically when a builder opens this repo.
    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
2026-10-02 Add per-episode watch links and a verified day-by-day table to PROGRAM.md
    Adds a "Watch: TODO-URL" line under each of the 13 episodes (TheMechanics
    to supply the real URLs -- never invented) and a full Day 1-20 reference
    table (scope, checkpoint, repo material, EQUIPMENT/WIRE_CONNECTIONS
    sections) for the AI Build Partner to read as its source of truth.
    Checkpoints are derived only from facts already in EQUIPMENT.md; no new
    specs invented. Existing episode text and chapter structure unchanged.
    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
2026-10-05 No-GPU path via the AI Partner; soften coding prerequisite
    ZOMA_AI_PARTNER.md: new guidance for when a builder has no local GPU
    -- offer to adapt the code (default to Claude instead of local Qwen,
    make Whisper's device configurable) rather than citing it as a dead
    end, clearly labelled as an untested DIY adaptation. Cross-linked from
    the existing "no local GPU" notes in ARCHITECTURE.md, STARTUP_GUIDE.md,
    EQUIPMENT.md, and from README's AI-partner section.
    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
2026-10-05 Add 3D design files from D drive
    [Battery_Case_v002.step, DRV8833_Platform_v001.step, Frame_Motor_Wires_v001.step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]
2026-10-05 Add 3D design files and models
    [Battery_Case_v002.step, DRV8833_Platform_v001.step, Frame_Motor_Wires_v001.step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]
2026-10-05 Upload complete 3d_design models and components
    [Battery_Case_v002.step, DRV8833_Platform_v001.step, Frame_Motor_Wires_v001.step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]
